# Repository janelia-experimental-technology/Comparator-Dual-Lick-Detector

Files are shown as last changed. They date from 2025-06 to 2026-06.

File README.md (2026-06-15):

# Comparator Dual Lick Detector
Mouse lick detector 

https://doi.org/10.25378/janelia.29685659

Summary

Lick sensors can be important tools in determining licking and drinking behavior of rodents during behavioral and neuroscience research. Commercially available lick sensors generally utilize either electrical, optical or force sensors in measuring licking and drinking behavior. A common problem with commercially available lick sensors is the production of significant electrical artifacts during recording of neural signals.

To measure neural signals without the production of electrical artifacts, researchers at Howard Hughes Medical Institute’s Janelia Research Campus have developed a Comparator Dual Lick Port Detector. The detector is designed to monitor a contact-type lick port without generating electrical interference on neural signals, to minimize sensation to subject animals and to allow fast detection of neural signals. The developed system modulates a signal at the lick port and analyzes the signal for changes due to attenuation (resistance change) or phase (due to capacitive change).

In “A low-cost solution to measure mouse licking in an electrophysiological setup with a standard analog-to-digital” by Abdallah Hayar, Jeri L. Bryant, John D. Boughter, and Detlef H. Heck in J Neurosci Methods (2006 June 15), a lick detection method is described that measures the potential difference caused by a rodent lick on a metal lick port using an analog-to-digital converter (ADC). The detection was robust and did not create artifacts in electrophysiological recordings. This method was tested at Janelia and found to work well. This novel system was designed to make the design cheaper and self-contained. An adjustable threshold comparator was substituted for the ADC and the circuit was opto-isolated.
Benefit

    Monitors a contact-type lick port without generating electrical interference on neural signals
    Enables fast detection time of less than one millisecond
    Minimizes sensations to subject animals thereby improving signal monitoring

Market Application

    Behavioral monitoring in animal research studies
    Animal research studies related primarily to neuronal circuit research

This design detects lick port licks using a method from:

A low-cost solution to measure mouse licking in an
electrophysiological setup with a standard analog-to-digital
converter

Abdallah Hayar, Jeri L. Bryant, John D. Boughter, and Detlef H. Heck*

A comparator is used in lieu of the ADC to create a simple circuit that outputs TTL levels.

The circuit can be built with or without electrical isolation.

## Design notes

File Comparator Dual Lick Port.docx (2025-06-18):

Comparator Dual Lick Port

Clarizen Project: P-270303

Junchol Park

Jianing Yu

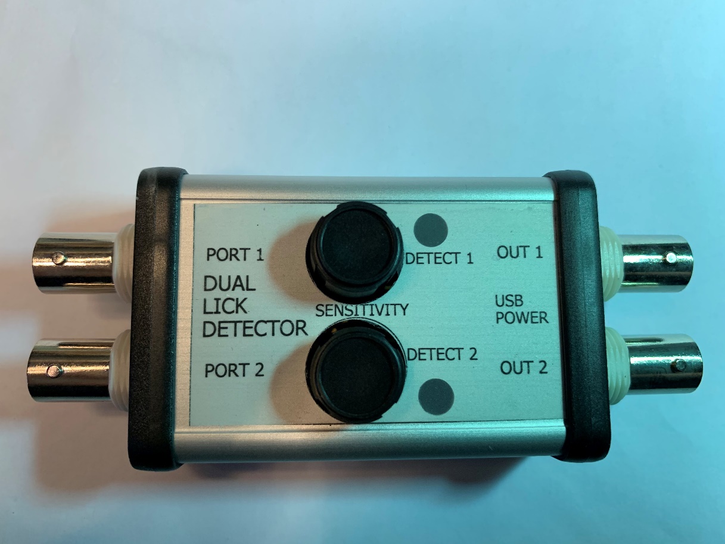
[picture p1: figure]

Steve Sawtelle
Engineer, ID&F

# System Overview

In “A low-cost solution to measure mouse licking in an electrophysiological setup with a standard analog-to-digital” by Abdallah Hayar, Jeri L. Bryant, John D. Boughter, and Detlef H. Heck in J Neurosci Methods (2006 June 15), a lick detection method is described that measures the potential difference caused by a rodent lick on a metal lick port using an analog-to-digital converter (ADC). The detection was robust and did not create artifacts in electrophysiological recordings. This method was tested at Janelia and found to work well. A circuit was designed to make the design cheaper and self-contained. An adjustable threshold comparator was substituted for the ADC and the circuit was opto-isolated.

# Hardware Development

A comparator was chosen to eliminate any high frequency digital noise in the detection circuit and make the design as simple as possible. A dual comparator was used to allow for two lick ports. Sensitivity of response for each port is provided by individual threshold adjustment trimmers. A single Maxim MAX9043 integrated circuit provides both detection channels and the threshold reference. In order to eliminate ground problems between the animal the instrumentation an Analog Devices ADUM5202 isolator is used to isolate the two detector outputs from the downstream instrumentation. It also provides isolated power to the comparator circuit. Connections are provided for LEDs so that lick detection can be checked by eye or put in the video field of view to synchronize licks to video observation. Power (no data) is supplied by a micro-USB cable.

Schematic

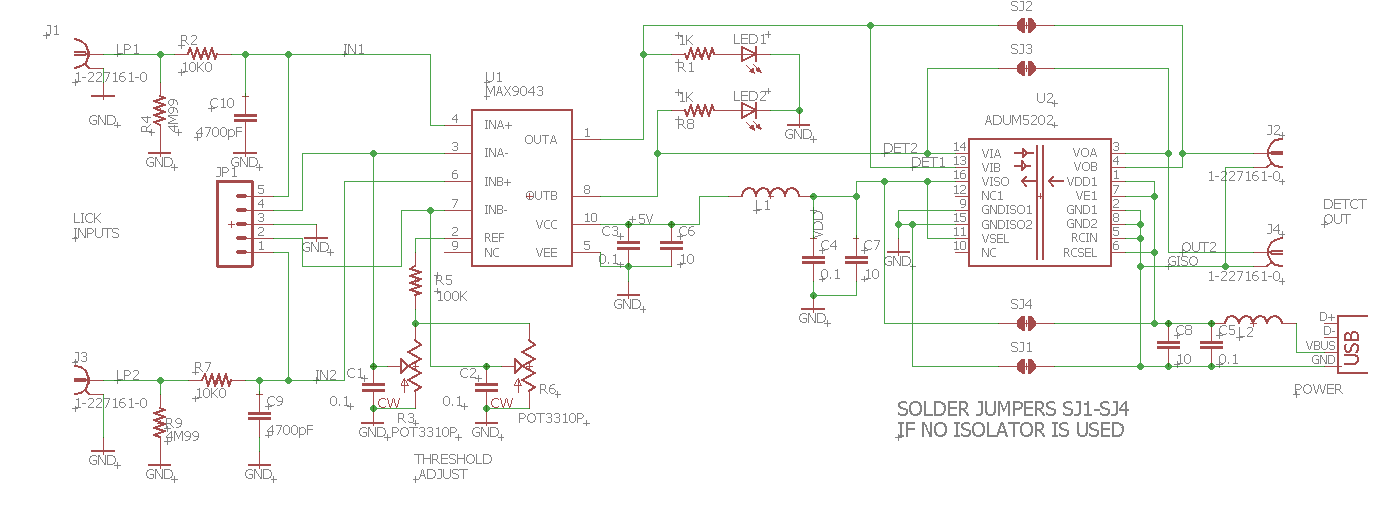
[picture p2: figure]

Materials

# Assembly, Test, and Calibration

The circuit includes an isolator chip to allow the lick sense ground and output grounds to electrically float relative to each other. If the isolator is not needed, it can be left off, in which case the 4 solder jumpers (SJ1-4) need to be solder bridged.

The board can be ordered from Oshpark via this link:

https://oshpark.com/shared_projects/CPSPhcF2

The connection to the lick port should be done through a short BNC cable with the center (signal) connection attached to the metal lick port tube. The outer (ground) connection should be attached to the animal ground. A good ground is required to minimize 60 Hz interference. It appears that the type of metal used for the ground connection can have a strong effect on the signal level. Generally dissimilar metals for the lick port and cage ground create the best signals (aluminum spout, stainless cage, for example.

The threshold will need to be adjusted to provide reliable output transitions. Adjust the potentiometer for each channel to provide good detections with no false detections.

Confidential Comparator Dual Lick Port

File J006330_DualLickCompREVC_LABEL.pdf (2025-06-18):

PORT 1

PORT 2

OUT 1

OUT 2

SENSITIVITY

DETECT 1

DETECT 2

USB
POWER

### DUAL LICK DETECTOR

PORT 1

PORT 2

OUT 1

OUT 2

SENSITIVITY

DETECT 1

DETECT 2

USB
POWER

### DUAL LICK DETECTOR

PORT 1

PORT 2

OUT 1

OUT 2

SENSITIVITY

DETECT 1

DETECT 2

USB
POWER

### DUAL LICK DETECTOR

PORT 1

PORT 2

OUT 1

OUT 2

SENSITIVITY

DETECT 1

DETECT 2

USB
POWER

### DUAL LICK DETECTOR

PORT 1

PORT 2

OUT 1

OUT 2

SENSITIVITY

DETECT 1

DETECT 2

USB
POWER

### DUAL LICK DETECTOR

PORT 1

PORT 2

OUT 1

OUT 2

SENSITIVITY

DETECT 1

DETECT 2

USB
POWER

### DUAL LICK DETECTOR

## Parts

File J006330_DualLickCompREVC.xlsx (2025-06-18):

Partlist exported from C:/PROJECTS/ID&F/MODULATED LICK PORT DETECTOR/ADC/ECAD/J006330_DualLickCompREVA.sch at 1/24/2018 9:41 AM
Qty | Value | Device | Designators | Manufacturer | Man PN | Vendor | Vendor PN | $ea | $Total | Notes
4 | BNC | CONN BNC JACK R/A 50 OHM PCB | J1 J2 J3 J4 | TE | 1-1634613-0 | DK | A97554-ND | $2.90 | $11.60
2 | Ferrite | FERRITE BEAD 2.5 KOHM 0805 1LN | L1 L2 | Samsung | CIM21J252NE | DK | 1276-6377-1-ND | $0.10 | $0.20
5 | 0.1 | CAPS0603S | C1 C2 C3 C4 C5 | Kemet | C0603C104K5RACTU | DK | 399-5089-1-ND | $0.10 | $0.50
2 | 1K | D12/CRCW0805-C 100 1K0 1% | R1 R8 | Vishay | CRCW08051K00FKEAC | DK | 541-3977-1-ND | $0.10 | $0.20
2 | 4M99 | RES SMD 4.99M OHM 1% 1/8W 0805 | R4 R9 | Vishay | CRCW08054M99FKEA | DK | 541-4.99MCCT-ND | $0.10 | $0.20
3 | 10 | CAP CER 10UF 10V X7R 0805 | C6 C7 C8 | Kemet | C0805C106M8RACTU | DK | 399-7413-1-ND | $0.55 | $1.65
2 | 10K | POT 10K OHM 1/4W PLASTIC LINEAR | R3 R6 | Bourns | 3310P-125-103L | DK | 3310P-125-103L-ND | $2.74 | $5.48
2 | 10K0 | D12/CRCW0805-C 100 10K 1% | R2 R7 | Vishay | CRCW080510K0FKEAC | DK | 541-3976-1-ND | $0.10 | $0.20
1 | 100K | D12/CRCW0805-C 100 100K 1% | R5 | Vishay | CRCW0805100KFKEAC | DK | 541-3978-1-ND | $0.10 | $0.10
1 | ADUM5202 | DGTL ISO 2.5KV GEN PURP 16SOIC | U2 | ADI | ADUM5202ARWZ | DK | ADUM5202ARWZ-ND | $10.12 | $10.12
1 | MAX9043 | IC COMPARATOR DUAL 10-UMAX | U1 | Maxim | MAX9043BEUB+ | DK | MAX9043BEUB+-ND | $1.70 | $1.70
1 | USB | CONN USB MICRO B RECPT SMT R/A | J100 | Amphenol | 10118194-0001LF | DK | 609-4618-1-ND | $0.46 | $0.46
2 | LED | LED 5MM VERT HE DIFF GRN PC MNT | LED1 LED 2 | Dialight | 5612201050F | DK | 350-2814-ND | $1.24 | $2.48
1 | PCB | printed circuit board |  | Oshpark | J006330_DualLickCompREVB |  |  | $12.00 | $12.00
2 | 0.1 | CAP CER 4700PF 50V C0G/NP0 0805 | C9 C10 | Murata | GRM2165C1H472JA01D | DK | 490-3044-1-ND | $0.22 | $0.44
1 | Enclosure | BOX ALUM NATURAL 2.36"L X 1.67"W |  | Hammond | 1455D601 | DK | HM1358-ND | $10.73 | $10.73
2 | Knob | KNOB PLASTIC .125 DIA BLACK |  | Grayhill | 11K5019-JCNB | DK | GH7660-ND | $0.87 | $1.74
 |  |  |  |  |  |  |  |  | $59.80

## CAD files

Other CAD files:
ADCLickPortEnclosure.dwg

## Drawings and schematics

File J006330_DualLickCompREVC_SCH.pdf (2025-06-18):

A

A

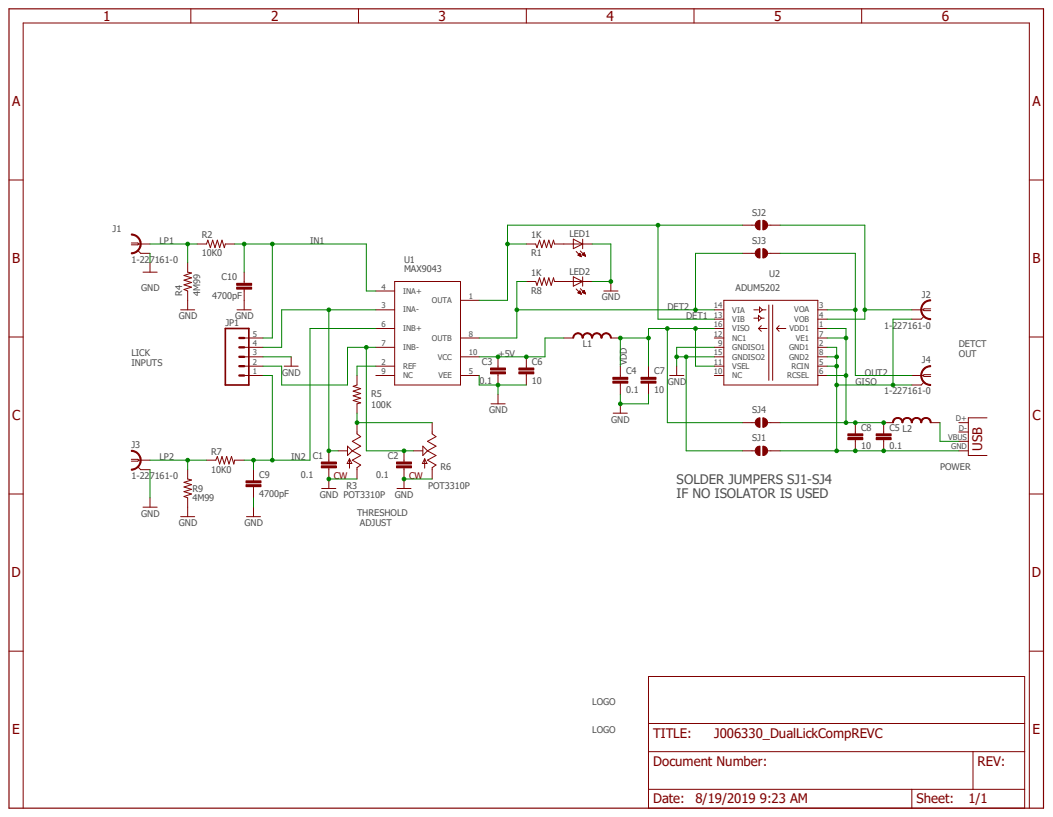
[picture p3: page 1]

SOLDER JUMPERS SJ1-SJ4
IF NO ISOLATOR IS USED

Document Number: | REV:

Date: 8/19/2019 9:23 AM | Sheet: 1/1

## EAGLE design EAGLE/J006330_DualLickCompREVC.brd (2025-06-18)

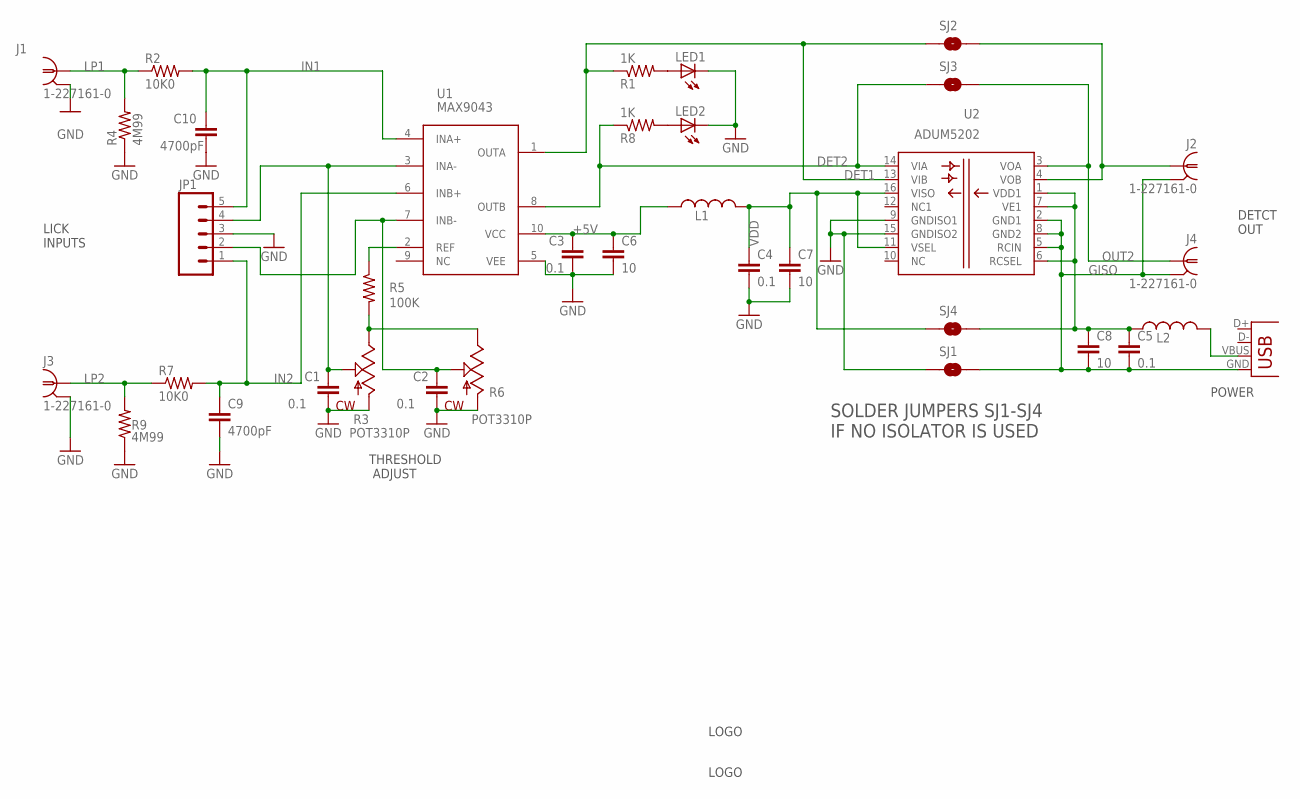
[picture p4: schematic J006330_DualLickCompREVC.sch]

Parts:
C1, C2, C3, C4, C5: 0.1; 0603S
C6, C7, C8: 10; 0805S
C9, C10: 4700pF; 0805S
J1, J2, J3, J4: 1-227161-0; AMP_227161
J100: USB; 10118194
JP1: M05LOCK; 1X05_LOCK
L1, L2: INDUCTOR_SM0805S; 0805S
LED1, LED2: LED5MM
R1, R8: 1K; 0805S
R2, R7: 10K0; 0805S
R3, R6: POT3310P; 3310P
R4, R9: 4M99; 0805S
R5: 100K; 0805S
SJ1, SJ2, SJ3, SJ4: SOLDERJUMPERNO; SJ_2S-NO
U1: MAX9043; UMAX10
U2: ADUM5202; SO-16-7.5MM
U$1: JFRC-LOGOLOGO_OP; LOGO_BMP_OP
U$2: JFRC-LOGOLOGO_JANELIA_2014_ECLOSURE; LOGO_JANELIA_2014_ENCLOSURE

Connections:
+5V: C3.1, C6.1, L1.1, U1.10 (VCC)
DET1: R1.1, SJ2.1, U1.1 (OUTA), U2.13 (VIB)
DET2: R8.1, SJ3.1, U1.8 (OUTB), U2.14 (VIA)
GISO: C5.2, C8.2, J2.2, J4.2, J100.GND, SJ1.2, U2.2 (GND1), U2.5 (RCIN), U2.8 (GND2)
GND: C1.2, C2.2, C3.2, C4.2, C6.2, C7.2, C9.2, C10.2, J1.2, J3.2, JP1.3, LED1.K (C), LED2.K (C), R3.1 (CCW), R4.1, R6.1 (CCW), R9.1, SJ1.1, U1.5 (VEE), U2.9 (GNDISO1), U2.15 (GNDISO2)
IN1: C10.1, JP1.5, R2.2, U1.4 (INA+)
IN2: C9.1, JP1.1, R7.2, U1.6 (INB+)
LP1: J1.1, R2.1, R4.2
LP2: J3.1, R7.1, R9.2
unnamed: J2.1, SJ2.2, U2.4 (VOB)
unnamed: LED1.A, R1.2
unnamed: R5.1, U1.2 (REF)
unnamed: R3.3 (CW), R5.2, R6.3 (CW)
unnamed: C1.1, JP1.4, R3.2 (W), U1.3 (INA-)
unnamed: LED2.A, R8.2
unnamed: J100.VBUS, L2.2
unnamed: C2.1, JP1.2, R6.2 (W), U1.7 (INB-)
OUT2: J4.1, SJ3.2, U2.3 (VOA)
VDD: C4.1, C7.1, L1.2, SJ4.1, U2.11 (VSEL), U2.16 (VISO)
VIN: C5.1, C8.1, L2.1, SJ4.2, U2.1 (VDD1), U2.6 (RCSEL), U2.7 (VE1)

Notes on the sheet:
LICK INPUTS
DETCT OUT
POWER
THRESHOLD ADJUST
SOLDER JUMPERS SJ1-SJ4 IF NO ISOLATOR IS USED

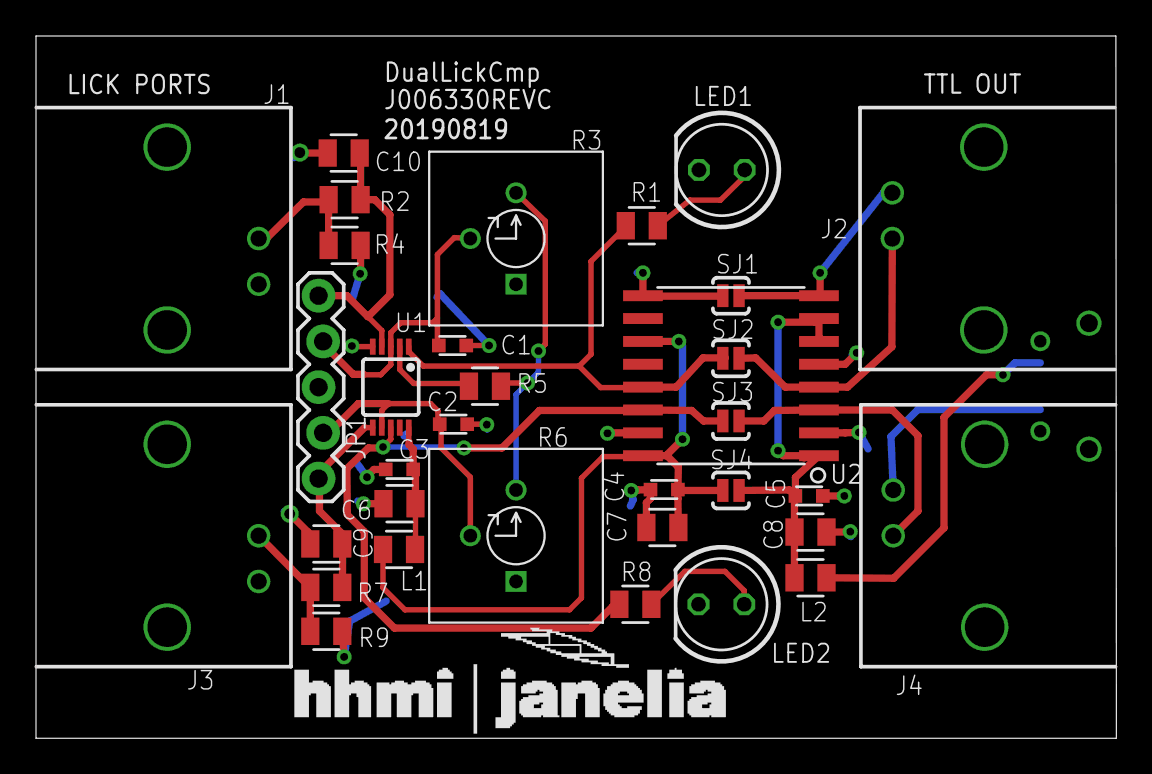
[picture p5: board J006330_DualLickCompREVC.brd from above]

Board: 2 copper layers, 60.0 x 39.0 mm, 37 parts (1 on the bottom side), 20 nets.

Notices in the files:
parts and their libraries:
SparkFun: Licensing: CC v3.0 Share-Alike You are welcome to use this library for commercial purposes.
